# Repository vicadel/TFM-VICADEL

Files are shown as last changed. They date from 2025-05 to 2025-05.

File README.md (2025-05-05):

# 3D-Printed Myoelectric Prosthesis Controlled by EMG Signals with BITalino Sensorization

## 📚 Project Description

This repository contains the complete development of the **Master's Thesis (TFM)** titled:

> **Design, Fabrication, and Optimization of a 3D-Printed Myoelectric Prosthesis Controlled by EMG Signals with BITalino Sensorization**

Authored by **Víctor Alonso del Moral** for the **Master's Degree in Electronic Engineering** at the **Universidad de Valencia (UV)**.

The project involves the design, manufacturing, and experimental validation of a robotic upper-limb prosthesis controlled via electromyographic (EMG) signals using the **BITalino kit** and an **ESP32** microcontroller. 
The system integrates computer vision control through **OpenCV**, and is optimized for 3D printing in **PETG** material.

---

## 📂 Repository Structure

- **README.md**: Main documentation.
- **LICENSE**: GNU GPL v3.0 license for open use.
- **docs/**: Full technical documentation (report, appendices, diagrams, 3D models).
- **hardware/**: 3D models (STL), electronic schematics (Fritzing), electronic configurations.
- **software/**:
  - **Arduino/**: Code for ESP32 (servo control, EMG interpretation).
  - **Python/**: Scripts for EMG data acquisition from BITalino and vision-based gesture control (OpenCV).
- **tests/**: Functional validation test results.
- **designs/**: CAD files for modified and custom-designed parts.

---

## 🛠️ Technologies Used

- **Microcontroller**: ESP32 WeMos R32 D1
- **Signal Acquisition System**: BITalino (r)evolution Plugged Kit BLE
- **EMG Sensors**: Aoutecen
- **Servomotors**: MG996R
- **3D Design**: SolidWorks, Tinkercad
- **Manufacturing**: FDM 3D Printing (PETG)
- **3D Printing Software**: Ultimaker Cura
- **Programming**: Arduino IDE, Python (PySerial, OpenCV)
- **Circuit Modeling**: Fritzing

---

## 🚀 Installation and Usage

1. Clone this repository:
   ```bash
   git clone https://github.com/vicadel/TFM-3D-Printed-Myoelectric-Prosthesis.git
   ```

2. Load the Arduino code:
   - Open Arduino IDE.
   - Select the `ESP32 Dev Module` board.
   - Upload the sketch from `software/Arduino/`.

3. Run the EMG acquisition system:
   - Install Python dependencies:
     ```bash
     pip install bitalino pyserial opencv-python
     ```
   - Run the EMG or vision control scripts from `software/Python/`.

4. Follow detailed instructions in `docs/memoria_TFM.pdf` for assembly, calibration, and testing.

---

## 📈 Project Status

✅ Mechanical design optimized  
✅ Functional EMG sensorization  
✅ Wireless control using ESP32  
✅ Gesture control via computer vision  
✅ Experimental validation completed

---

## 🔮 Future Work

- Integration of artificial intelligence for EMG gesture recognition.
- Development of a mobile app for calibration and control.
- Design of a custom PCB for system integration.
- Implementation of haptic feedback systems.

---

## 📜 License

This project is licensed under the **GNU General Public License v3.0**.  
See the `LICENSE` file for more details.

---

## 🙌 Acknowledgements

- Thanks to the Open Source community for providing essential tools.
- Personal thanks to my family and friends for their constant support.

---

> Created with passion, dedication, and a drive for innovation. 🚀

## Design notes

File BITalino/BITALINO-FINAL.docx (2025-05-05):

# 6.7. Adquisición de Señales EMG con BITalino: Fundamentos, Procesamiento y Aplicaciones

## 6.7.1. Introducción a la Adquisición de Señales EMG

El kit BITalino (r)evolution Plugged Kit BLE/BT es una plataforma modular de adquisición biomédica diseñada específicamente para facilitar el estudio, la monitorización y la integración de señales fisiológicas en contextos portátiles y de investigación aplicada. Está compuesto por una unidad central de control (MCU) y una serie de módulos sensores enchufables que permiten la captación precisa de biopotenciales como EMG, ECG y EEG, además de otras variables como la conductancia de la piel (EDA), la aceleración (ACC) o la temperatura corporal.

Cada módulo de BITalino ha sido diseñado para cumplir los requisitos específicos de su tipo de señal, con una arquitectura electrónica independiente que incluye preamplificación, filtrado analógico, acondicionamiento y salida analógica ya lista para ser digitalizada por la MCU. La placa base incluye un sistema de adquisición con resolución de 10 bits, transmisión Bluetooth 4.0 BLE y conectividad por UART, lo que permite tanto la transmisión inalámbrica de datos en tiempo real como su almacenamiento para análisis posteriores.

3.2 Funcionamiento interno del sistema BITalino

El funcionamiento del sistema puede dividirse en cinco etapas principales:

1. Captación de la señal:
- A través de electrodos de superficie (Ag/AgCl) conectados directamente a los sensores modulares.
- El tipo de electrodos y su colocación son clave para garantizar una captación de señal limpia, especialmente en señales EMG.
2. Acondicionamiento analógico en el módulo sensor:
- Cada módulo contiene un amplificador de instrumentación de alta ganancia (1009 para EMG). Elimina señales comunes con CMRR > 80 dB.
- Se aplica un filtro analógico paso banda específico del tipo de señal (ej. EMG: 20–500 Hz).
- Alta impedancia de entrada para evitar pérdida de señal debido al contacto con la piel.
3. Conversión Analógico-Digital (ADC):
- El módulo MCU centraliza la conversión con una resolución de 10 bits (1024 niveles).
- Se digitalizan las señales preacondicionadas que llegan de los módulos por cable Plugged.
- El muestreo puede configurarse entre 1 Hz y 1000 Hz (valor típico en EMG: 1000 Hz).
4. Multiplexación y estructura de paquetes:
- Cada canal se multiplexa y se estructura en tramas tipo UART (8N1) o BLE.
- Las tramas digitales incluyen cabecera, ID de canal, timestamp y valor digitalizado.
5. Transmisión inalámbrica o por cable:
- BLE: permite comunicación con PC, móviles, microcontroladores o apps como OpenSignals.
- UART: conexión a software como OpenSignals o a microcontroladores como la ESP32.

3.3. BITalino: Módulos Disponibles y Aplicación en la Adquisición de EMG

- EMG (Electromiografía): Captura señales eléctricas generadas por la actividad muscular.
- ECG (Electrocardiografía): Registra la actividad eléctrica del corazón.
- EDA (Actividad Electrodérmica): Mide la conductancia de la piel relacionada con la respuesta fisiológica emocional.
- ACC (Acelerómetro): Detecta movimiento y orientación espacial en tres ejes.
- LUX (Sensor de luz): Mide la intensidad de luz ambiental.
- Temperatura: Registra la temperatura corporal o ambiental.
- EEG (Electroencefalografía): Captura señales cerebrales para análisis neuronal.
- MCU (Potencia y Comunicación): Centraliza la gestión del sistema, proporcionando comunicación Bluetooth.
- BTN (Push Button): Interruptor digital para sincronización y marcado manual de eventos.

Estos módulos pueden conectarse e integrarse de forma flexible, permitiendo adaptarse a diversas aplicaciones biomédicas, deportivas y de investigación.

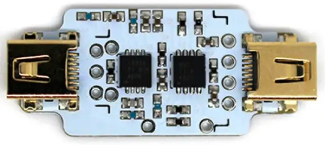
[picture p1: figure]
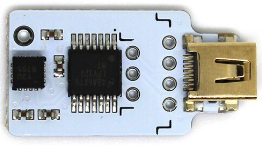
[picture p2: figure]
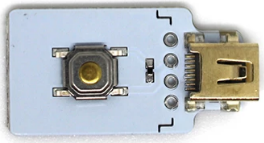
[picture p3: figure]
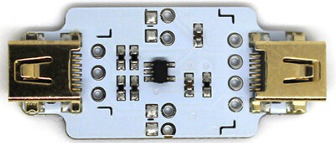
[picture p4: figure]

Ilustración 1 - Vista general de los diferentes módulos que componen el ecosistema BITalino: sensores de EMG, EDA, ACC, ECG, EEG, temperatura, luz, pulsador y módulo MCU. Cada uno de ellos se puede intercambiar e integrar en configuraciones personalizadas según la aplicación biomédica deseada.
(Agradecimientos a pluxbiosignals.com)

### 3.4. Módulos candidatos para la Adquisición y Análisis de señales EMG

En el apartado anterior se han mencionado los diferentes sensores disponibles en BITalino. Sin embargo, en este apartado nos centraremos exclusivamente en aquellos que pueden utilizarse en la adquisición de señales EMG, fundamentales para el análisis de la actividad muscular, el control de dispositivos y la investigación biomédica. La correcta selección y combinación de estos sensores permite una adquisición más precisa y completa de la señal, reduciendo la presencia de artefactos y mejorando la interpretación de los datos.

## 3.1 Módulo EMG (Electromiografía)

El módulo EMG de BITalino es el sensor principal para la medición de la actividad muscular, utilizado para la medición del electromiograma. Su funcionamiento se basa en la detección de los impulsos eléctricos generados por la contracción de los músculos, capturados mediante electrodos superficiales colocados estratégicamente sobre la piel.

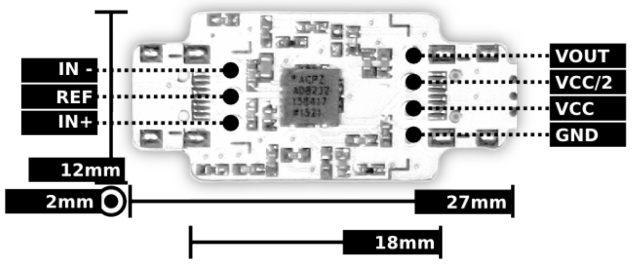
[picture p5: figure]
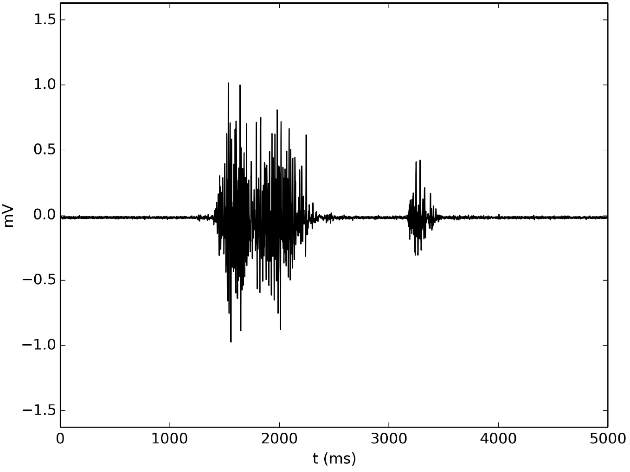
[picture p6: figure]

Ilustración 2 - Vista del módulo EMG con sus conexiones de entrada y salida, junto a una señal EMG real en milivoltios captada durante la contracción muscular (Agradecimientos a pluxbiosignals.com)

Este sensor cuenta con una alta ganancia para amplificar la señal y permitir su procesamiento sin pérdidas. Además, incorpora un filtrado para reducir interferencias externas, como el ruido de la red eléctrica o los artefactos generados por el movimiento del usuario.

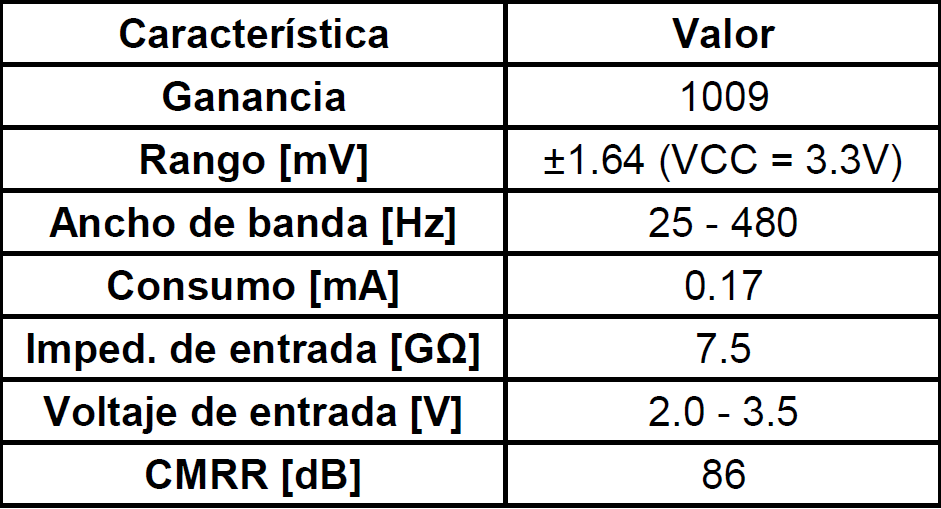
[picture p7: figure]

Tabla 1 – Características principales del Módulo EMG

Una característica fundamental del módulo EMG es su alta impedancia de entrada, lo que permite captar señales de baja amplitud con precisión, minimizando los efectos de la resistencia de contacto entre la piel y los electrodos. La calidad de la señal puede verse afectada por factores como la sudoración, la colocación de los electrodos o la presencia de ruido electromagnético en el entorno.

Este sensor opera dentro de un rango de voltajes óptimo para integrarse en sistemas embebidos, gracias a su bajo consumo energético, es ideal para aplicaciones portátiles. Su uso es común en el desarrollo de prótesis controladas por EMG, estudios de ergonomía, monitorización del rendimiento muscular en el deporte y rehabilitación de pacientes con trastornos neuromusculares.

Otro aspecto relevante es la conversión de los valores digitales adquiridos mediante el ADC para obtener representaciones en unidades de milivoltios. Para esto, se emplea una función de transferencia específica que tiene en cuenta la ganancia del sensor y el voltaje de referencia.

### 5.1.1 Función de Transferencia para el Sensor EMG

La conversión de los valores digitales obtenidos mediante el ADC a unidades de voltaje en el sensor EMG se realiza mediante la siguiente ecuación, permitiendo transformar los datos adquiridos en valores comprendidos entre -1.64 mV y 1.64 Mv.

3.1 Etapas del procesamiento de señal

1. Captura por electrodos: Configuración bipolar con tres electrodos: activo (+), referencia (-), y tierra. Deben colocarse alineados con las fibras musculares.
2. Amplificación diferencial: Con ganancia fija de 1009. Elimina señales comunes con CMRR > 80 dB.
3. Filtrado analógico: Filtro paso-banda entre 20–500 Hz.
4. Conversión analógico-digital (ADC): Resolución de 10 bits. Frecuencia de muestreo ajustable; 1000 Hz utilizada en este proyecto.
5. Transmisión: Vía BLE o UART a software como OpenSignals o a microcontroladores como la ESP32.

EMG(V)=(((ADC)/(2^n)-1/2)×VCC)/(G_(EMG))

EMG(mV)=EMG(V)×1000

Donde:

- VCC representa la tensión de alimentación del sensor, cuyo valor es 3.3V.
- G_(EMG) es la ganancia del sensor, establecida en 1009.
- ADC se refiere al valor digital obtenido en el proceso de conversión.
- n es la resolución del conversor analógico-digital, con un valor por defecto de 10 bits.

## 5.2 Módulo EDA (Actividad Electrodérmica)

El sensor EDA de BITalino está diseñado para medir la actividad electrodérmica de la piel, proporcionando información sobre la conductancia cutánea. Aunque su función principal está enfocada en estudios de respuestas fisiológicas relacionadas con el estrés o la actividad del sistema nervioso autónomo, también puede complementar la adquisición de señales EMG.

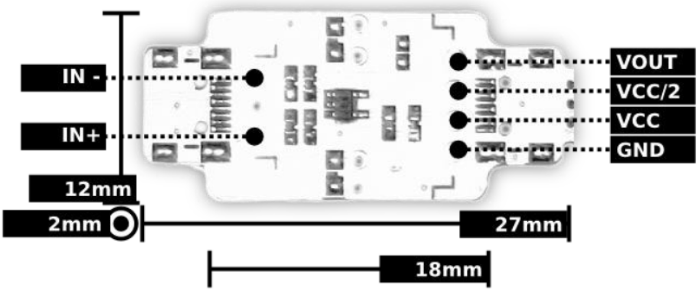
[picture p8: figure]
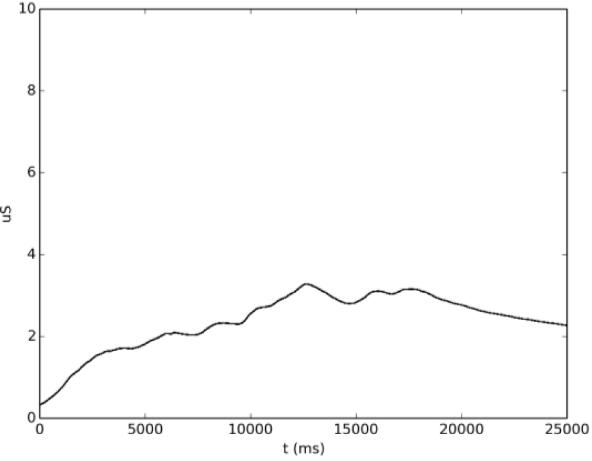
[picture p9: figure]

Ilustración 3 - Imagen del sensor EDA con su esquema de pines y gráfica de conductancia (en µS) frente al tiempo, correspondiente a una respuesta fisiológica gradual.
(Agradecimientos a pluxbiosignals.com)

3.X.1 Etapas del procesamiento de señal EDA

1. Captura por electrodos: Se utilizan dos electrodos colocados en las falanges distales de los dedos índice y medio de la mano no dominante.
2. Conversión de resistencia a voltaje: La variación de la resistencia de la piel es transformada en un voltaje proporcional por medio de un divisor resistivo interno.
3. Filtrado analógico: Se utiliza un filtro pasa-bajo para eliminar ruido de alta frecuencia y garantizar estabilidad de la señal.
4. Conversión analógico-digital (ADC): Resolución de 10 bits, con una frecuencia de muestreo más baja que EMG (recomendada: 10–100 Hz).
5. Transmisión: Vía BLE o UART para su análisis en OpenSignals o software personalizado.

El principio de funcionamiento del sensor EDA se basa en la variación de la resistencia de la piel, la cual cambia según el nivel de hidratación y la actividad de las glándulas sudoríparas. Estos cambios se traducen en variaciones en la conductancia cutánea, las cuales son captadas mediante electrodos y convertidas en una señal eléctrica proporcional. La presencia de sudor, por ejemplo, aumenta significativamente la conductividad entre los electrodos, lo que puede afectar la calidad de otras señales fisiológicas como la EMG, al modificar el contacto piel-electrodo.

Su integración junto al módulo EMG en entornos de adquisición multisensorial permite estudiar la relación entre la activación muscular y el estado fisiológico del usuario. Esto resulta especialmente útil en contextos de fatiga muscular, análisis de estrés o sistemas de biofeedback. Además, el módulo EDA de BITalino destaca por su bajo consumo energético y alta sensibilidad, lo que lo convierte en una herramienta eficaz en investigaciones de neurociencia, psicología aplicada y control de interfaces basadas en parámetros fisiológicos.

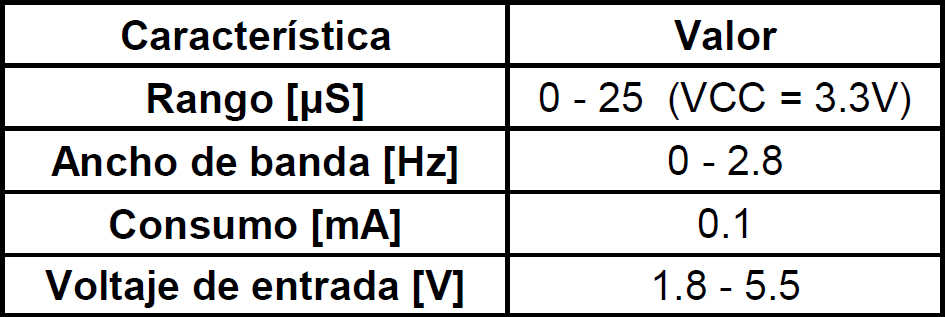
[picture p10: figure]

Tabla 2 - Características principales del Módulo EDA

### 5.2.1 Función de Transferencia para el Sensor EDA

El sensor de actividad electrodérmica (EDA) convierte la resistencia de la piel en valores de conductancia expresados en microsiemens (μS). La ecuación que rige esta transformación es:

R(MΩ)=1- (ADC)/(2^n)

EDA(μS)=1/(R(MΩ))

Donde:

- R(MΩ) representa la resistencia medida por el sensor en megaohmios.
- ADC es el valor digitalizado obtenido de la señal.
- n corresponde al número de bits de resolución del ADC, fijado en 10 bits por defecto.

"La frecuencia de muestreo recomendada para la señal EDA es menor en comparación con la EMG, ya que la respuesta galvánica de la piel varía lentamente. Además, el uso de electrodos de plata/cloruro de plata (Ag/AgCl) mejora la estabilidad de la medición y reduce la impedancia de contacto, optimizando la calidad de la señal."

## 5.3 Módulo ACC (Acelerómetro)

El módulo ACC de BITalino mide la aceleración en tres ejes espaciales, proporcionando datos sobre el movimiento y la orientación del dispositivo. Aunque no mide directamente la actividad muscular, su uso combinado con el sensor EMG permite mejorar el análisis de la señal al correlacionarla con el movimiento del cuerpo.

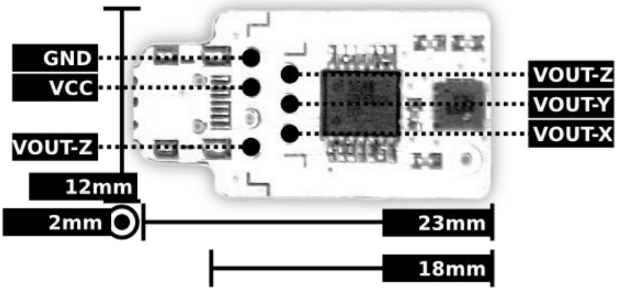
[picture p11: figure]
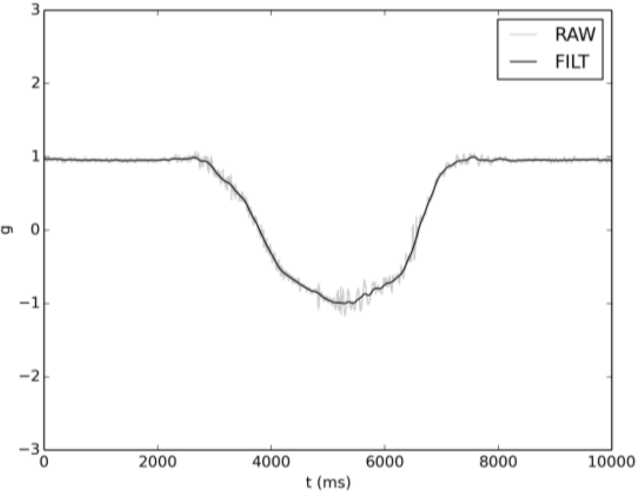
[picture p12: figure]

Ilustración 4 - Representación del acelerómetro con salidas por eje (X, Y, Z), junto a una señal de aceleración donde se compara la señal sin filtrar y la filtrada. (Agradecimientos a pluxbiosignals.com)

3.X.1 Etapas del procesamiento de señal

1. Captura por sensores MEMS: Cada eje del acelerómetro capta variaciones de aceleración debidas al movimiento.
2. Conversión de aceleración a voltaje: El sensor MEMS produce un voltaje analógico proporcional a la aceleración detectada.
3. Filtrado analógico: Se aplica un filtro pasa-bajo interno para evitar oscilaciones de alta frecuencia y ruidos mecánicos.
4. Conversión analógico-digital (ADC): Conversión a 10 bits por canal; frecuencia típica: 100–500 Hz.
5. Transmisión: Enviado vía BLE o UART en tiempo real.

El sensor ACC de BITalino permite medir la aceleración en los tres ejes del espacio (X, Y, Z), siendo una herramienta clave en estudios de biomecánica, rehabilitación y control por gestos. Su integración junto al módulo EMG facilita el análisis conjunto de la postura, el desplazamiento y la activación muscular, lo cual resulta útil en el estudio de la marcha, análisis ergonómico o sistemas de asistencia robótica.

Además, el acelerómetro resulta esencial para detectar y corregir artefactos de movimiento en las señales EMG. Al identificar aceleraciones bruscas, el sistema puede discernir entre una contracción muscular real y una alteración debida a desplazamiento involuntario del sensor. Su bajo consumo energético y alta sensibilidad lo hacen adecuado para sistemas portátiles, permitiendo una monitorización continua sin comprometer la autonomía. También destaca por su capacidad para registrar cambios sutiles, lo que lo hace especialmente valioso en estudios de control motor y equilibrio postural.

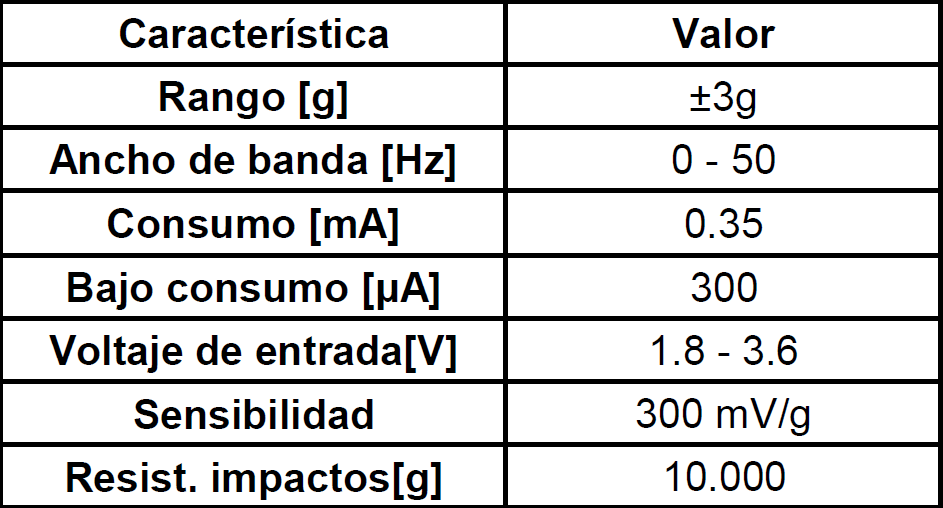
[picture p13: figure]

Tabla 3 - Características principales del Módulo ACC

### 5.3.1 Función de Transferencia para el Sensor ACC

El sensor acelerómetro convierte los valores digitales adquiridos por el ADC en aceleración expresada en g (gravedad terrestre). La ecuación utilizada para esta conversión es:

ACC(g)=(ADC-C_(min))/(C_(max-) C_(min))×2-1

Donde:

- ADC es el valor digital obtenido por el convertidor analógico-digital.
- C_(min) representa el menor valor registrado durante la calibración del sensor.
- C_(max) es el valor máximo captado durante la calibración.

Para calibrar correctamente el acelerómetro, se recomienda realizar una rotación completa de 360° en cada eje, asegurando que se alcancen los valores de referencia de ±1 g. El rango de medición del módulo ACC de BITalino es de ±3 g, suficiente para la mayoría de las aplicaciones biomédicas y ergonómicas. Para mejorar la estabilidad de la señal y reducir el ruido, se aconseja aplicar filtrado digital pasa-bajo o promediar los datos adquiridos.

## 5.4 Módulo BTN (Push Button)

El módulo BTN de BITalino es un interruptor digital que permite detectar pulsaciones momentáneas. Aunque no es un sensor fisiológico, su integración en sistemas de adquisición de señales EMG permite la sincronización y el marcado de eventos.

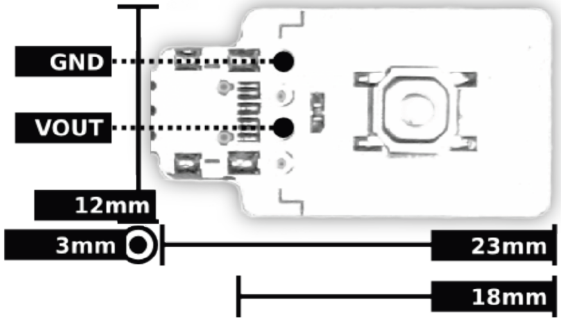
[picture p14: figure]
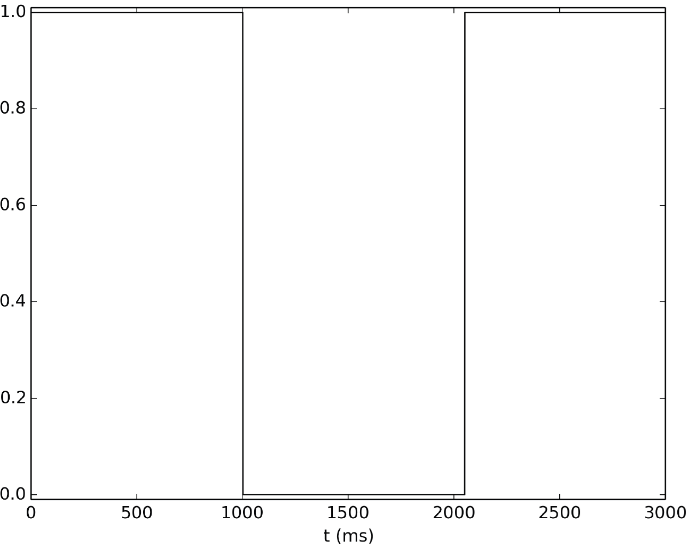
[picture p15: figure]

Ilustración 5 - Visualización del módulo de botón junto a una señal binaria en función del tiempo, que indica la detección de dos pulsaciones momentáneas. (Agradecimientos a pluxbiosignals.com)

3.X.1 Etapas del procesamiento de señal

1. Activación por usuario: Pulsación manual sobre el botón.
2. Lectura de estado digital: El estado del botón es leído como alto (1) o bajo (0).
3. Debouncing electrónico: Se elimina el rebote mediante un filtro RC o digital (firmware).
4. Codificación digital: La transición de estado se codifica en un paquete binario.
5. Transmisión: Se envía mediante BLE o UART para sincronizar eventos en OpenSignals o microcontroladores.

Tabla 4 - Características principales del Módulo BTN

El módulo BTN se utiliza principalmente como herramienta de control dentro de experimentos donde es necesario identificar momentos clave en la adquisición de señales fisiológicas. Su función más habitual es la marcación de eventos, como el inicio o el fin de una contracción muscular voluntaria durante pruebas con EMG, facilitando la posterior segmentación y análisis de los datos registrados. También puede utilizarse en sistemas interactivos como confirmación o activación de comandos dentro de un flujo de control.

Gracias a su diseño de bajo consumo energético y su integración directa con el resto de los módulos del sistema BITalino, el botón permite sincronización precisa de eventos en tiempo real. Su tiempo de respuesta es prácticamente instantáneo, lo que lo hace ideal para protocolos que requieren alta precisión temporal, como el control de prótesis, estudios de activación muscular o biofeedback. Su simplicidad y eficacia lo convierten en una herramienta auxiliar muy valiosa dentro de sistemas de adquisición multisensorial.

Conclusión

El sistema BITalino, mediante su arquitectura modular y su compatibilidad con múltiples señales fisiológicas, ha demostrado ser una herramienta versátil para la adquisición y análisis biomédico. En este proyecto se han analizado sus cuatro módulos principales: EMG, EDA, ACC y BTN. Cada uno de ellos aporta información complementaria que permite una caracterización más completa de la actividad del usuario. El EMG ha sido la base para la detección de contracciones musculares, el EDA permite interpretar el estado autonómico, el ACC añade contexto cinemático al movimiento corporal, y el BTN aporta control manual y marcado de eventos clave.

Si bien todos los módulos han sido utilizados durante la fase experimental para comprender su comportamiento y posibilidades de integración, únicamente el EMG ha sido implementado de forma funcional en los códigos del TFM. Este módulo ha permitido controlar en tiempo real la prótesis robótica desarrollada, mediante programación en Python y comunicación con una placa ESP32. La integración completa del resto de módulos, especialmente con técnicas de fusión sensorial y algoritmos de aprendizaje automático, se plantea como un avance futuro que permitirá dotar al sistema de mayor robustez, adaptabilidad y precisión en entornos dinámicos reales.

## 6. Proceso Técnico de Adquisición de la señal

### 6.1. Captura y Adquisición Inicial de la Señal EMG

La adquisición de señales EMG con BITalino comienza con la colocación precisa de electrodos superficiales sobre el músculo de interés. Se recomienda el uso de electrodos pre-gelificados para asegurar una baja impedancia y un contacto estable. La configuración preferida es la bipolar, donde dos electrodos activos se colocan alineados con las fibras musculares, y un electrodo de referencia se sitúa en una región ósea o de baja actividad muscular, como el codo o la clavícula.

BITalino emplea sensores EMG en configuración bipolar, lo cual representa una elección técnica clave frente a la alternativa unipolar. Esta configuración bipolar permite una mayor inmunidad al ruido de modo común, lo que mejora notablemente la calidad de la señal y reduce las interferencias externas, algo fundamental en aplicaciones como el control de prótesis o el análisis de la actividad muscular. Además, al colocar dos electrodos activos directamente sobre el músculo, se logra una detección más precisa y localizada, ideal para estudios donde se requiere alta resolución, como en biofeedback o rehabilitación. A diferencia de la configuración unipolar, que es más vulnerable al ruido y menos específica, la bipolaridad garantiza una mayor fiabilidad, simplicidad en el montaje y robustez durante el uso, especialmente en entornos no clínicos como el educativo o de investigación aplicada. Por tanto, remarcar que el sistema BITalino trabaja con sensores bipolares es esencial para justificar tanto el diseño del sistema como la calidad de los resultados obtenidos.

### 6.2. Amplificación Diferencial y Filtrado Analógico

Tras la captura inicial, la señal EMG, típicamente de muy baja amplitud (aproximadamente entre 5 y 20 µV), es sometida a una amplificación diferencial mediante circuitos integrados específicos del módulo EMG del BITalino. Este amplificador posee una ganancia alta (aproximadamente 1009) y un alto rechazo del modo común (CMRR) de 86 dB para minimizar ruido y artefactos externos.

Simultáneamente, se aplican filtros analógicos integrados que operan en un rango de frecuencia de 20-500 Hz para eliminar interferencias de baja frecuencia (movimiento, respiración) y alta frecuencia (ruido electromagnético).

### 6.3. Conversión analógico-digital (ADC)

La señal analógica amplificada y filtrada se convierte a formato digital mediante un conversor analógico-digital (ADC) de 10 bits, integrado en el sistema BITalino. Este ADC tiene una tasa de muestreo ajustable, típicamente configurada a 1000 Hz, cumpliendo el teorema de Nyquist para capturar señales EMG sin aliasing hasta frecuencias de 500 Hz:

f_(muestreo) ≥2× f_(maxEMG)

### 6.4. Procesamiento Digital Avanzado

La señal digitalizada EMG se procesa mediante varias etapas técnicas detalladas a continuación:

- Filtrado Digital Avanzado: Implementación de un filtro digital Butterworth paso-banda de cuarto orden (20-500 Hz) mediante software específico como OpenSignals o directamente en ESP32. Esto permite una limpieza adicional y más precisa de la señal capturada.
- Rectificación de la Señal: La señal EMG, originalmente alternante (AC), se rectifica mediante:

EMG_(rect(t)) =|EMG(t)|

Este paso convierte la señal en positiva, facilitando el análisis posterior de la envolvente muscular.

- Suavizado y Extracción de la Envolvente: Para obtener una representación más clara y continua de la actividad muscular, se aplica un filtro digital de media móvil o un filtro paso-bajo con ventana de suavizado de aproximadamente 0.5 segundos:

EMG_(suave(t) =) 1/N ∑_(i=t)^(t+N-1) EMG_(rect(i))

Este proceso estabiliza la señal y permite un análisis más preciso y menos susceptible al ruido residual.

### 6.5. Extracción de Características Específicas

La señal suavizada pasa por la extracción de características fundamentales para análisis cuantitativo y control protésico. Las características típicas incluyen:

- RMS (Root Mean Square):

√(1/N ∑_(i=1)^N EMG^2 _(rect) (i))

- Valor Medio Absoluto (MAV):

1/N∑_(i=1)^N |EMG(i)|

Estas características proporcionan parámetros sólidos para el reconocimiento y control preciso basado en EMG.

6.6 Pruebas experimentales de adquisición de señales EMG en el hombro y antebrazo con BITalino.

Con el objetivo de identificar las ubicaciones más eficaces para la adquisición de señales electromiográficas (EMG) aplicadas al control de una prótesis mioeléctrica, se ha desarrollado un protocolo experimental basado en la utilización del kit BITalino (r)evolution Plugged Kit BLE/BT. El enfoque adoptado se centra en una configuración distribuida de hasta nueve electrodos por prueba, empleando cuatro sensores BITalino simultáneamente. Esto permite evaluar la calidad y estabilidad de las señales recogidas en diferentes regiones musculares del miembro superior y el muñón, así como su pertinencia para su integración en algoritmos de control protésico.

6.6.1 Configuración de pruebas y distribución de electrodos

Se diseñaron pruebas experimentales enfocadas en dos zonas clave del miembro superior: el hombro y el antebrazo. En cada una se colocaron 9 electrodos (4 sensores) para evaluar la calidad y estabilidad de las señales EMG en diferentes regiones musculares implicadas en el control de una prótesis mioeléctrica.

- Prueba 1: Zona del hombro

Objetivo: Registrar actividad del deltoides y estabilizadores en movimientos articulares.

- Sensor 1 (3 electrodos): Deltoides anterior/posterior, tierra en clavícula.
- Sensor 2 (2 electrodos): Deltoides medio.
- Sensor 3 (2 electrodos): Trapecio superior.
- Sensor 4 (2 electrodos): Pectoral mayor.

Movimientos: Apertura/cierre de la mano, rotación de muñeca, posiciones y dedos.

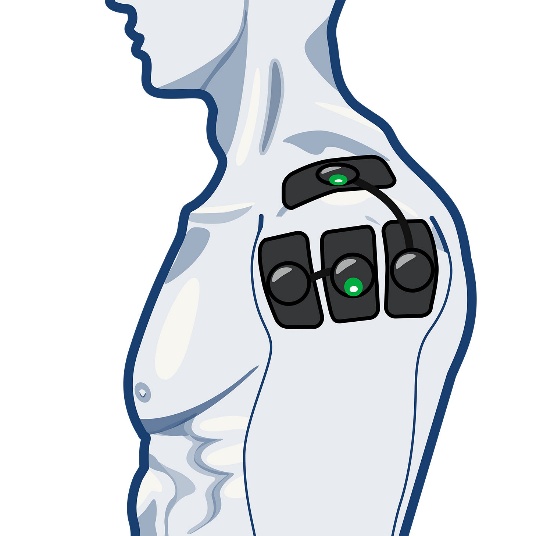
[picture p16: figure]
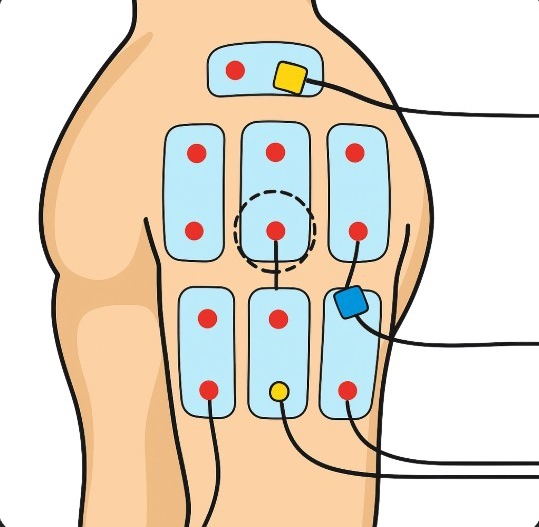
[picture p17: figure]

Ilustración 6 – Ejemplo visual de colocación de los electrodos en la zona del hombro

- Prueba 2: Zona del antebrazo

Objetivo: Captar señales durante flexión/extensión de muñeca y dedos.

- Sensor 1 (3 electrodos): Flexores superficiales de los dedos, tierra sobre superficie ósea.
- Sensor 2 (2 electrodos): Extensores comunes de los dedos.
- Sensor 3 (2 electrodos): Pronador redondo.
- Sensor 4 (2 electrodos): Supinador largo.

Movimientos: Apertura/cierre de la mano, rotación de muñeca, posiciones y dedos.

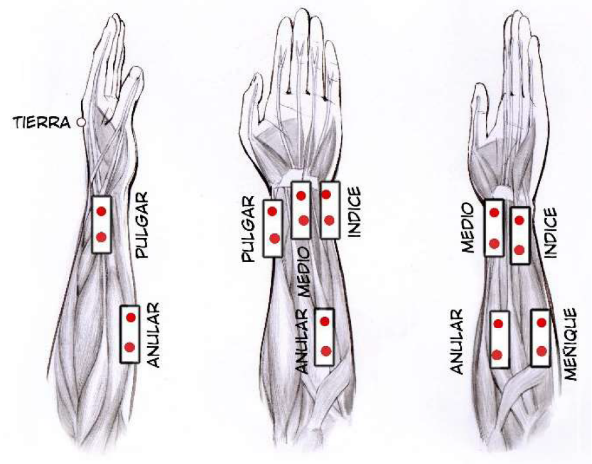
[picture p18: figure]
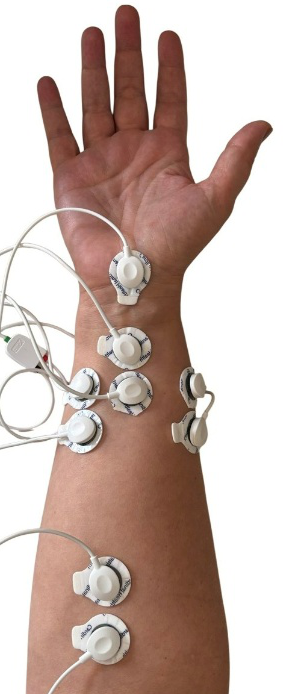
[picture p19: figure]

6.7 Configuración detallada de OpenSignals para la adquisición EMG

OpenSignals es el software oficial desarrollado por PLUX para la adquisición, visualización y exportación de datos capturados con los dispositivos BITalino. Su interfaz intuitiva y altamente configurable permite adaptar cada sesión experimental a las necesidades técnicas del estudio, garantizando calidad de señal, trazabilidad y compatibilidad con análisis posteriores.

6.7.1 Parámetros clave de configuración

- Tasa de muestreo seleccionada: La señal EMG contiene frecuencias de hasta 500 Hz. Según el teorema de Nyquist, para evitar aliasing y pérdida de información, es necesario muestrear al menos al doble de esa frecuencia. 1000 Hz permite capturar de forma precisa los detalles temporales y espectrales de la señal.
- Filtro digital aplicado: Elimina componentes de baja frecuencia (movimiento, respiración) y ruido de alta frecuencia (EMI).
- Visualización en tiempo real con envolvente: Permite observar la activación muscular con mayor claridad y detectar patrones en tiempo real.
- Grabación en formato .CSV: Pemite exportar los datos para análisis posteriores en MATLAB o Python.
- Conversión activada: Activar la opción "Converted Values" permite visualizar y exportar los datos directamente en milivoltios, aplicando internamente la función de transferencia del sensor EMG.
- Trigger (disparo por evento): Permite marcar el inicio de un ejercicio o una contracción muscular, sincronizando la señal con el instante deseado.

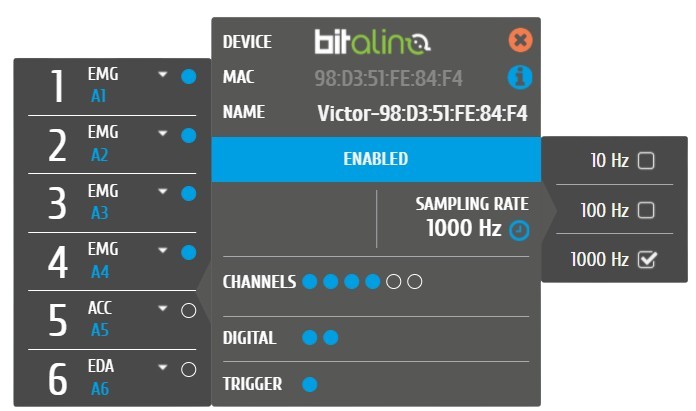
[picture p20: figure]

Ilustración 9 - Vista general del panel de conexión al kit BITalino y Pantalla de configuración del dispositivo en OpenSignals, donde se muestra la tasa de muestreo configurada a 1000 Hz, la activación de cuatro canales EMG (A1–A4), un canal de acelerómetro (A5) y EDA (A6). Se observa también la activación de los canales digitales y la función de trigger para registrar eventos (Agradecimientos a pluxbiosignals.com)

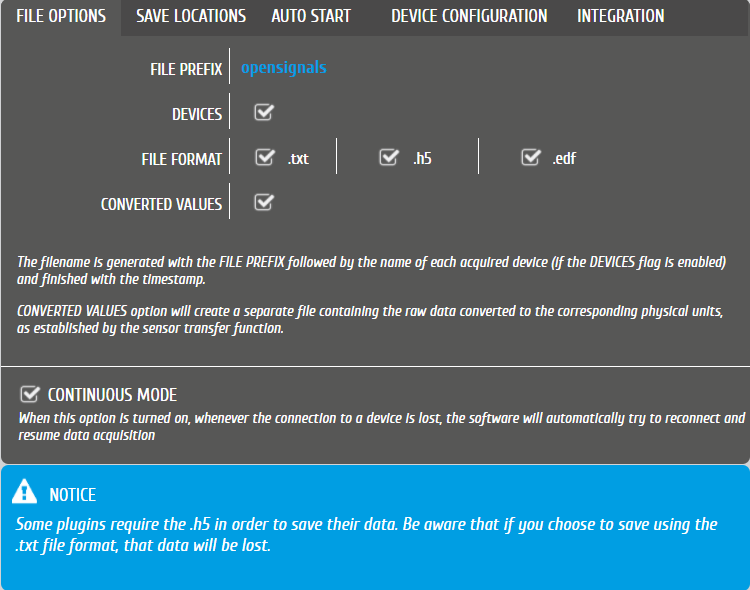
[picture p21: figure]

Ilustración 10 - Panel de configuración de guardado de datos donde se selecciona el formato de archivo (.txt, .h5, .edf), el prefijo del archivo, y la opción “Converted Values”, que permite exportar los datos con unidades físicas aplicando la función de transferencia (Agradecimientos a pluxbiosignals.com))

6.7.3 Integración con sensores complementarios

- Alta fidelidad de señal: con 1000 Hz se garantiza la captura de todo el contenido útil sin distorsión.
- Flexibilidad experimental: parámetros fácilmente adaptables según el tipo de sensor o el objetivo del experimento.
- Compatibilidad: OpenSignals exporta formatos estándar, permitiendo trabajar sin restricciones en entornos de análisis personalizados.
- Consumo de recursos: altas tasas de muestreo generan más datos, por lo que es importante planificar el almacenamiento y procesamiento previo.
- Sinergia con módulos adicionales: Durante la adquisición con OpenSignals, se utilizaron también módulos complementarios del sistema
- Combinaciones recomendadas:
- EMG + ACC: Reconocimiento de gestos + eliminación de interferencias por movimiento.
- EMG + EDA: Correlación entre fatiga muscular y respuesta electrodérmica.
- EMG + BTN : Segmentación precisa mediante pulsación sincronizada.

6.7.4 Ventana EMG Muscle Activations y ajustes recomendados

La ventana "EMG Muscle Activations" de OpenSignals permite detectar eventos musculares clave y personalizar filtros, unidades y parámetros de suavizado para facilitar el análisis. A continuación, se describen sus secciones principales y recomendaciones de configuración adaptadas al uso del kit BITalino en prótesis controladas por EMG:

- Asignación de disparador digital (ASSIGN DIGITAL TRIGGER)
- Permite asignar un canal digital como referencia para marcar eventos (por ejemplo, un botón físico).
- Si no se utilizan entradas digitales, puede ignorarse.
- Detección de activaciones (FIND ALL MUSCLE ACTIVATIONS)
- Detecta eventos basados en cambios digitales o temporales.
- Recomendación para BITalino:
- Opción: FROM DIGITAL ON TO 0.3 SEC
- Justificación: ajusta una ventana de detección para activar servos tras una contracción mantenida.

Opciones avanzadas de procesamiento (ADVANCED OPTIONS)

- Unidad: mV (milivoltios), ideal para precisión con señales crudas.
- Filtros recomendados:
- Bandpass: 20–500 Hz, orden 4 → ideal para capturar contenido útil EMG.
- Highpass y Lowpass opcionales según ruido presente.

Opciones de detección de activación (ACTIVATION DETECTION OPTIONS)

- Signal Smooth Window(0.5s): Suaviza sin perder respuesta rápida.
- Process on Another Channel: Desactivado, a menos que se use referencia cruzada.

Resultados de activación muscular (MUSCLE ACTIVATION RESULTS)

- Se muestra la contracción máxima (MVC) por canal:
- Si los valores son muy bajos (< 0.05 mV), ajustar filtros y trigger.

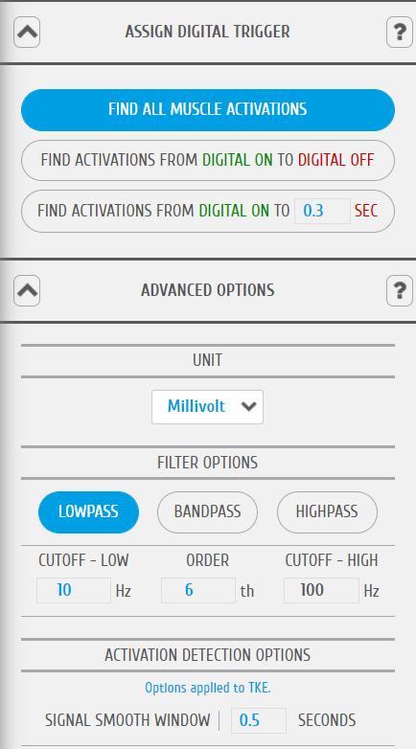
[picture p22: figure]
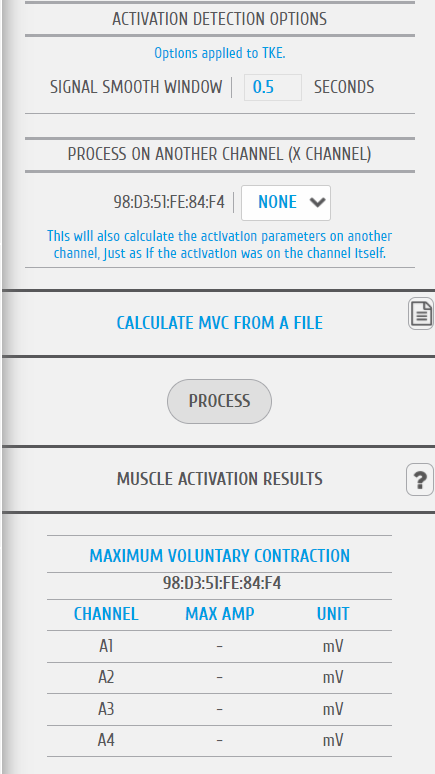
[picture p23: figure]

Ilustración 8 – (a) CoSe muestra la interfaz para detección de activaciones musculares en OpenSignals, incluyendo la asignación del trigger digital, el modo de detección por umbral temporal, y la selección de filtros. Se destacan la unidad en milivoltios, el filtro pasa banda recomendado (20–500 Hz) y la ventana de suavizado ajustada a 0.5 s.nfiguración avanzada de filtros y activación en la ventana EMG Muscle Activations. (b) Pantalla de resultados generados por la herramienta de activación muscular en OpenSignals. Muestra el uso de la opción “Process”, los ajustes de ventana de suavizado y canal, y los valores de máxima contracción para los canales A1 a A4 (Agradecimientos a pluxbiosignals.com)

Configuración óptima recomendada para tu sistema:

- Unidad: mV
- Filtro: Bandpass 500–1000 Hz, orden 4
- Ventana de suavizado: 0.5 s
- Trigger de activación: OFF o 0.3s

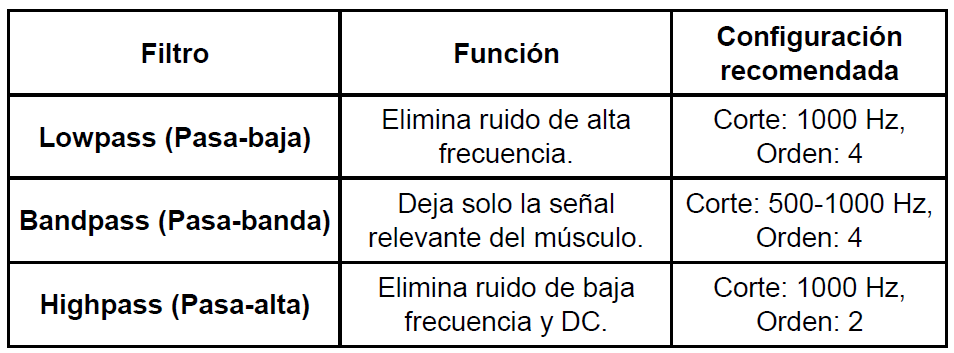
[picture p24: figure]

Ilustración 7 - Opciones de filtros para ayudar a mejorar la calidad de la señal EMG

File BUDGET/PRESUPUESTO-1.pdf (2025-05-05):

Nombre de la pieza | Parte Mecánica | Relleno(%) | Soporte | Pared(mm) | Peso (gr) | Precio(€)
i2_BASESOPORTE | i2_RightHand | 90 | Si | 3 | 800 | 16
i2_Adapter1109MG | i2_RightHand | 90 | Si | 3 | 65 | 1,3
i2_CoverFingerV3 | i2_RightHand | 90 | Si | 3 | 20 | 0,6
i2_FingersMoldX5V3 | i2_RightHand | 90 | Si | 3 | 100 | 2
i2_FingersTipX5V2 | i2_RightHand | 90 | Si | 3 | 30 | 0,6
i2_FingersX5V2 | i2_RightHand | 90 | Si | 3 | 75 | 1,5
i2_HandCover | i2_RightHand | 90 | Si | 3 | 78 | 1,6
i2_HandCover | i2_RightHand | 90 | Si | 3 | 72 | 1,5
i2_PalmCoverV2 | i2_RightHand | 90 | Si | 3 | 65 | 1,3
i2_PalmPDI | i2_RightHand | 90 | Si | 3 | 44 | 0,9
i2_PulleyX5V1 | i2_RightHand | 90 | Si | 3 | 15 | 0,3
i2_WristGearV1 | i2_RightHand | 90 | Si | 3 | 50 | 0,6
i2_WristLargeV2 | i2_RightHand | 90 | Si | 3 | 110 | 2,2
TOTAL I2_RIGHTHAND | | | | | 1524 30,4
Nombre de la pieza | Parte Mecánica | Relleno(%) | Soporte | Pared(mm) | Peso (gr) | Precio(€)
RobCableBackV3 | Forearm-servo-bed | 90 | Si | 3 | 14 | 0,4
RobCableFrontV3 | Forearm-servo-bed | 90 | Si | 3 | 17 | 0,45
RobRingV3 | Forearm-servo-bed | 90 | Si | 3 | 14 | 0,4
RobServoBedV6 | Forearm-servo-bed | 90 | Si | 3 | 47 | 1
Servo-pulleyX5 | Forearm-servo-bed | 90 | Si | 3 | 12 | 0,3
TensionerRightV1 | Forearm-servo-bed | 90 | Si | 3 | 15 | 0,35
TOTAL FOREARM | | | | | 119 2,9
Nombre de la pieza | Parte Mecánica | Relleno(%) | Soporte | Pared(mm) | Peso (gr) | Precio(€)
Bolt_entretoise7 | Right-Hand | 90 | Si | 3 | 15 | 0,35
Robpart2V4 | Right-Hand | 90 | Si | 3 | 40 | 1
Robpart3V4 | Right-Hand | 90 | Si | 3 | 51 | 1,3
Robpart4V4 | Right-Hand | 90 | Si | 3 | 66 | 1,8
Robpart5V4 | Right-Hand | 90 | Si | 3 | 83 | 2,15
TOTAL RIGHTHAND | | | | | 255 6,6
Nombre de la pieza | Parte Mecánica | Relleno(%) | Soporte | Pared(mm) | Peso (gr) | Precio(€)
CableHolderWristV5 | Rotation-Wrist | 90 | Si | 3 | 6 | 0,15
RotaWrist1V4 | Rotation-Wrist | 90 | Si | 3 | 41 | 1
RotaWrist2V3 | Rotation-Wrist | 90 | Si | 3 | 22 | 0,5
RotaWrist3V3 | Rotation-Wrist | 90 | Si | 3 | 11 | 0,3
WristGearsV5 | Rotation-Wrist | 90 | Si | 3 | 12 | 0,3
TOTAL ROTATION-WRIST | | | | | 92 2,25
Peso (gr) | Precio(€)
PRESUPUESTO TOTAL PROTESIS | 1990 42,15

# Presupuesto apartado Bloque Mecánico Impresión 3d Peso y Precio

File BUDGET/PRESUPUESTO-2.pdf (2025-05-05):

Componentes | Cantidad | Precio unitario (€) | Precio total (€)
BITalino (r)evolution Plugged Kit BLE/BT | 1 | 226,87 | 226,87
Sensor Cable | 4 | 12,1 | 48,4
2-Lead Electrode Cable | 4 | 18,15 | 72,6
3-Lead Electrode Cable | 1 | 23,59 | 23,59
700 mAh 3.7V Battery | 1 | 9,68 | 9,68
(EMG) Sensor | 5 | 12,1 | 60,5
3D Printed Box | 1 | 12,1 | 12,1
Ag/AgCl Electrodes (50) | 1 | 30,25 | 30,25

483,99

## Presupuesto apartado Instrumentación y Adquisición de señal

Presupuesto total apartado Instrumentacion y Adquisición de

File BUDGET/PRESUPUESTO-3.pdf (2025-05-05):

Componentes | Cantidad | Precio unitario (€) | Precio total (€)
ESP32 Wemos R32 | 1 | 6,99 | 6,99
Shield V5 | 1 | 3,5 | 3,5
HC-05 Bluetooth Module | 1 | 4,89 | 4,89
12V – 5V Convertidor | 1 | 3,29 | 3,29
Switch | 10 | 0,143 | 1,43
T Connector | 10 | 0,226 | 2,26
Push Button | 10 | 0,242 | 2,42
Slide Switch | 10 | 0,114 | 1,14
RGB LED (Cátodo Común) | 1 | 0,189 | 0,189
1000mAh 11.1VBattery | 1 | 12,99 | 12,99
Total | 46 | | 39,099
Componentes | Cantidad | Precio unitario (€) | Precio total (€)
Tornillos M3 x 16mm | 100 | 0,03 | 3
Tornillos M3 x 4mm | 100 | 0,02 | 2
Tornillo M3 x 12mm | 20 | 0,05 | 1
Tornillos M1.5 x 4mm | 100 | 0,03 | 3
Muelles 3/16″ x 1-3/4 | 10 | 0,25 | 2,5
Total | 330 | | 11,5
Componentes | Cantidad | Precio unitario (€) | Precio total (€)
Servomotores SG-90 | 10 | 1,1 | 11
Servomotores PDI-6225 | 6 | 5 | 30
Servomotores MG996R | 6 | 4,5 | 27
Sensores Hall AH3503 | 10 | 0,2 | 2
Imánes (2.5x1mm) | 100 | 0,01 | 1
Total | 132 | | 71
Componentes | Cantidad | Precio unitario (€) | Precio total (€)
Cinta de 16 hilos de 3 metros | 1 | 3 | 3
Cable de pesca 0.8x200LB | 3 | 15 | 15
Tubo de teflón 1.5X 2.5-1m | 6 | 1,5 | 9
Total | 10 | | 27

148,599

Componentes Eletrónicos

Tornillería y fijaciones

Motores y Sensores

Cables y líneas de conexión

PRESUPUESTO TOTAL COMPONENTES

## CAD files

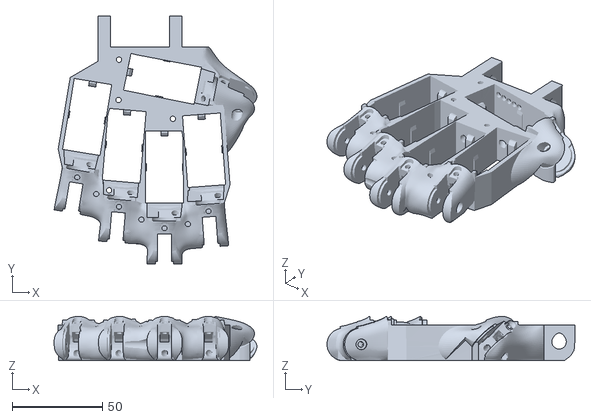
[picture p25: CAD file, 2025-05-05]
PLANOS STL/i2HandVicadel/i2_WristLargeV2.stl
112.6 x 137.7 x 24.5

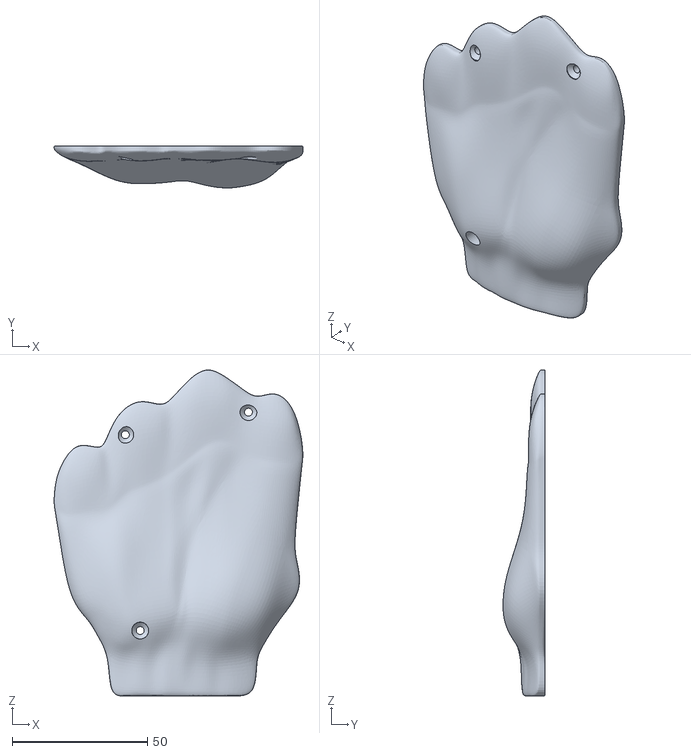
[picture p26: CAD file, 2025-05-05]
PLANOS STL/i2HandVicadel/i2_PalmCoverV2.stl
92.0 x 15.5 x 120.7

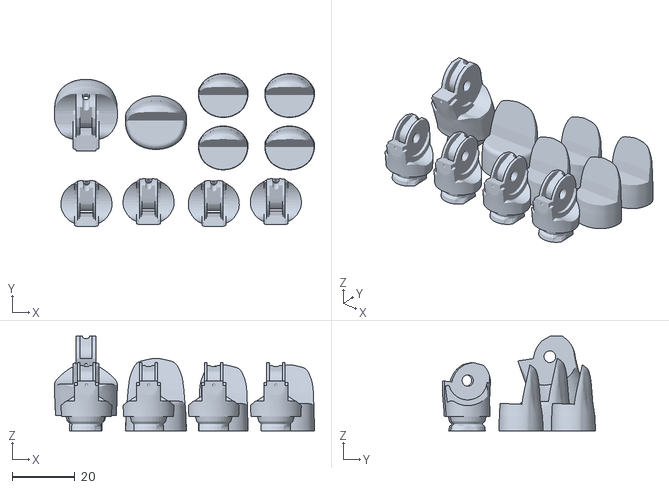
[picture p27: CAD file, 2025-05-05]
PLANOS STL/i2HandVicadel/i2_FingersTipX5V2.stl
82.9 x 48.7 x 30.2

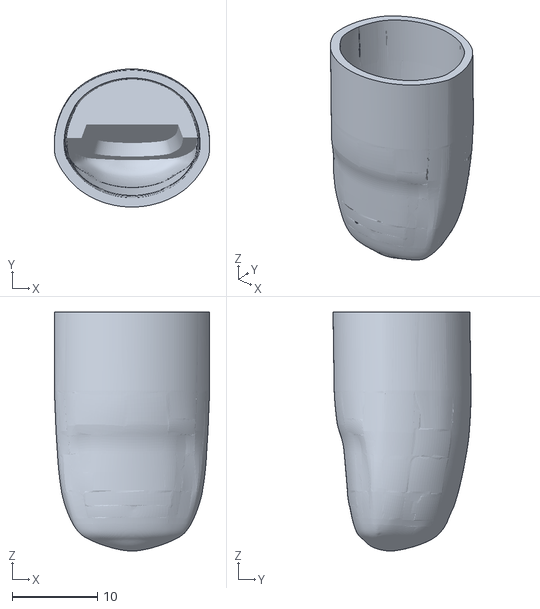
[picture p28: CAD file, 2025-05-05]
PLANOS STL/i2HandVicadel/Finger_TipV1_with_shallow_magnet_hole.stl
18.3 x 16.2 x 28.1

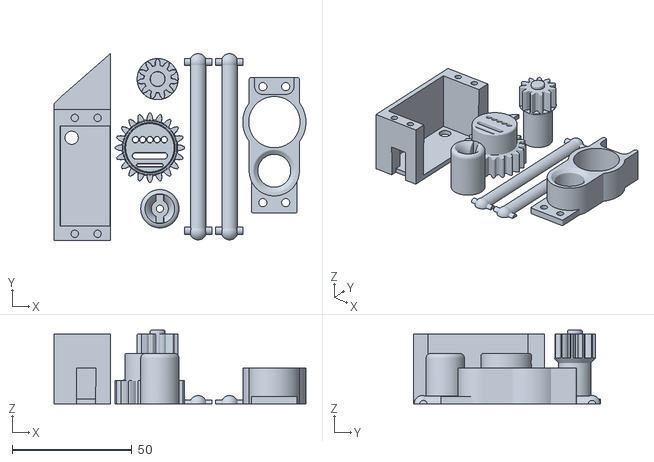
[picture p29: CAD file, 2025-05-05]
PLANOS STL/i2HandVicadel/i2_WristGearV1.stl
105.2 x 78.1 x 30.8

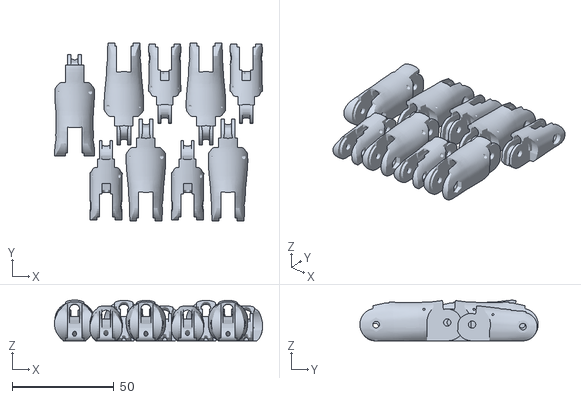
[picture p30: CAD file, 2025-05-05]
PLANOS STL/i2HandVicadel/i2_FingersX5V2.stl
102.3 x 87.7 x 20.0

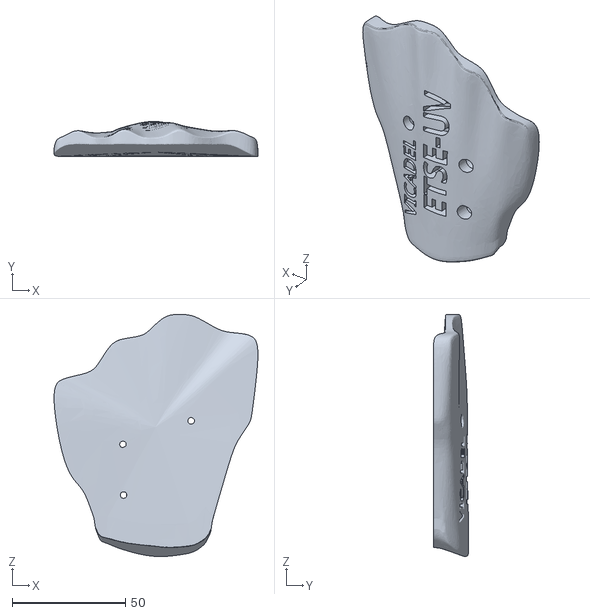
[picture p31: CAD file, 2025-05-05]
PLANOS STL/i2HandVicadel/Mano 2 ETSE.stl
90.2 x 15.6 x 107.0

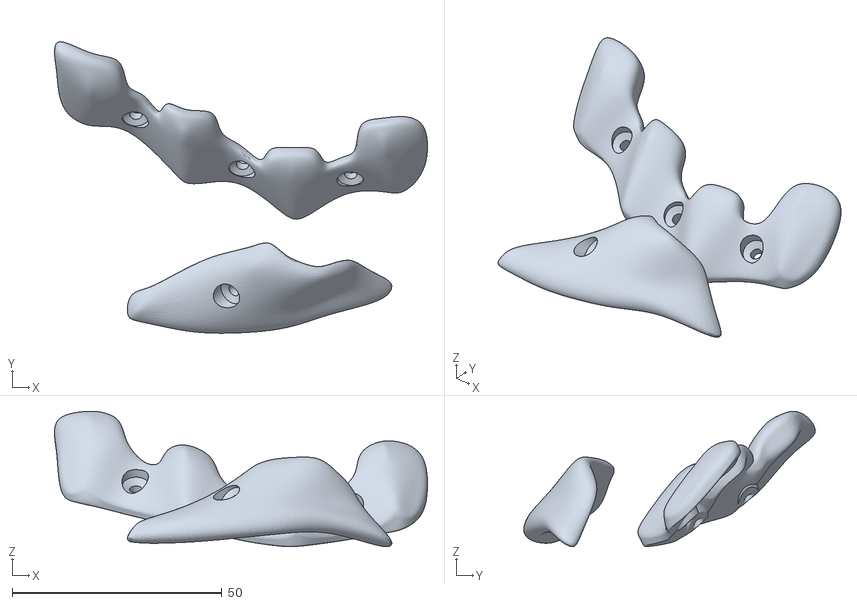
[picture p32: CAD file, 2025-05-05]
PLANOS STL/i2HandVicadel/i2_CoverFingerV3.stl
89.0 x 69.6 x 32.3

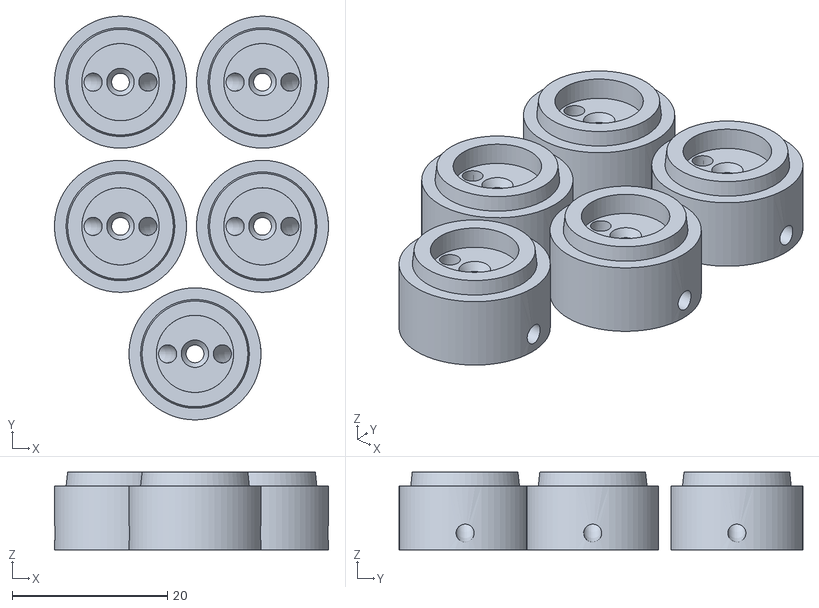
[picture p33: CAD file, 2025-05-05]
PLANOS STL/i2HandVicadel/i2_PulleyX5V1.stl
35.3 x 52.0 x 10.0

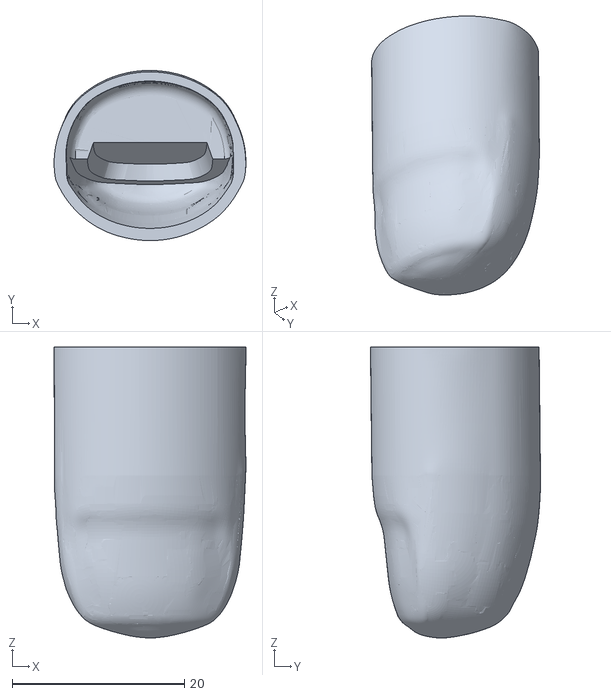
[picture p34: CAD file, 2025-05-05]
PLANOS STL/i2HandVicadel/Thumb_TipV2_with_shallow_magnet_hole.stl
22.3 x 19.8 x 33.8

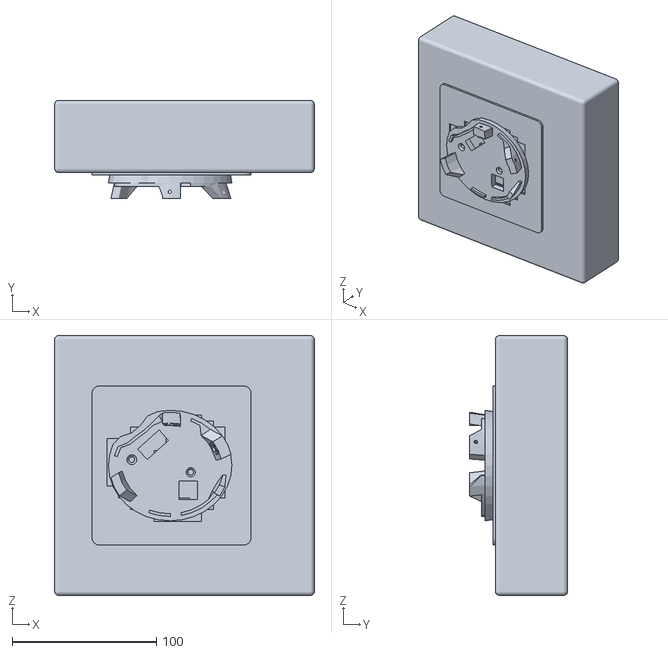
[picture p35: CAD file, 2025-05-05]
PLANOS STL/i2HandVicadel/BASE SOPORTE.stl
180.0 x 68.0 x 180.0

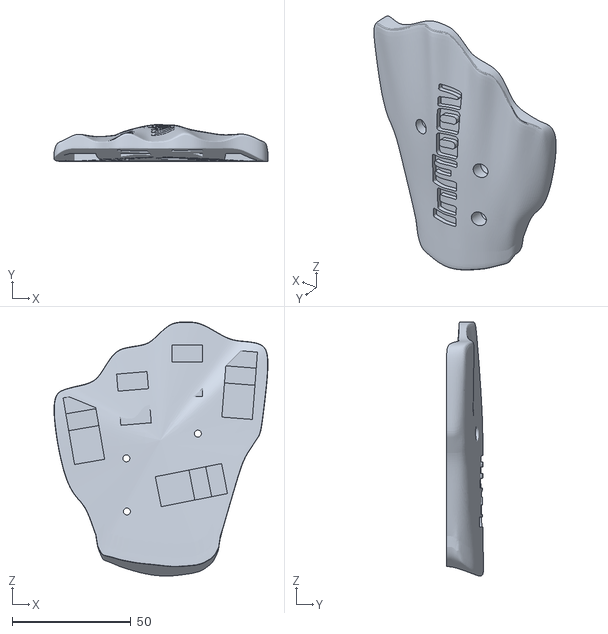
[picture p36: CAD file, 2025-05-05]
PLANOS STL/i2HandVicadel/i2_HandCoverV2.stl
90.2 x 15.6 x 107.1

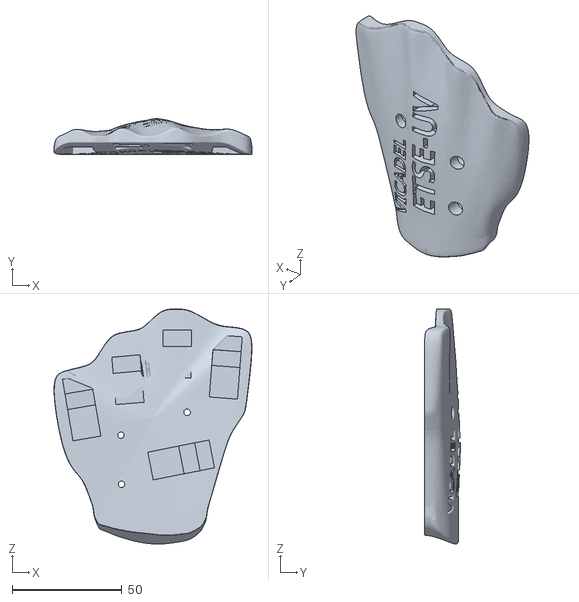
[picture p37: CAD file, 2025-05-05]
PLANOS STL/i2HandVicadel/Mano 1 ETSE.stl
90.2 x 16.3 x 107.1

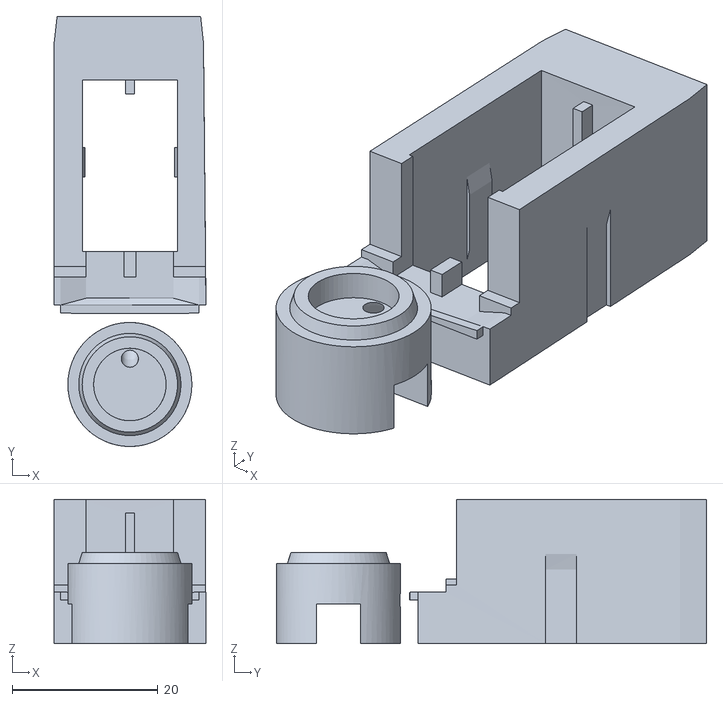
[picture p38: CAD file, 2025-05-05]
PLANOS STL/i2HandVicadel/i2_Adapter1109MG.stl
20.8 x 58.9 x 19.8

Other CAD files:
PLANOS STL/i2HandVicadel/i2_PalmPDI6225V3.stl
PLANOS STL/i2HandVicadel/i2_FingersMoldX5V3.stl
PLANOS STL/i2HandVicadel/i2_HandCoverV1.stl

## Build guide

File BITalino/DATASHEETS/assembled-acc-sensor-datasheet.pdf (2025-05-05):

# Accelerometer (ACC)

Assembled Sensor Data Sheet | BUNDLE-ACC-UCE6-Z/XYZ
| 221220

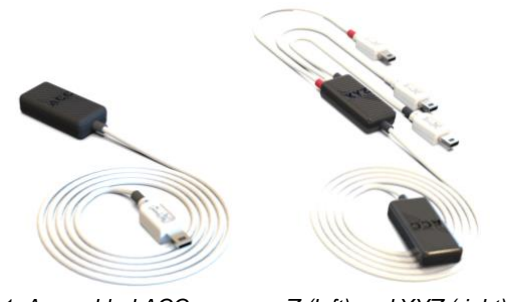
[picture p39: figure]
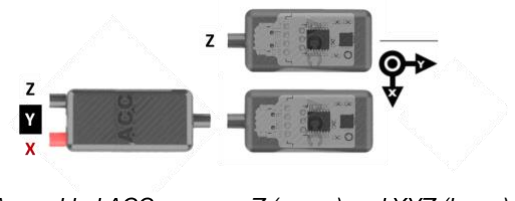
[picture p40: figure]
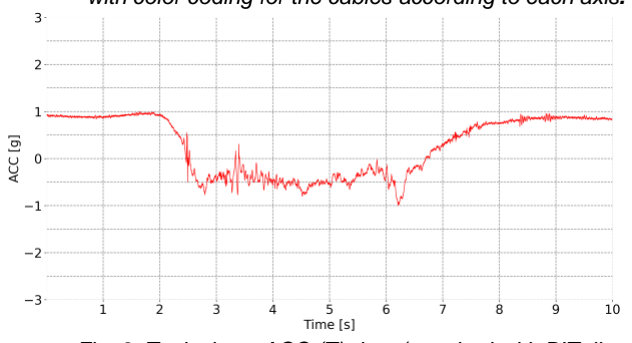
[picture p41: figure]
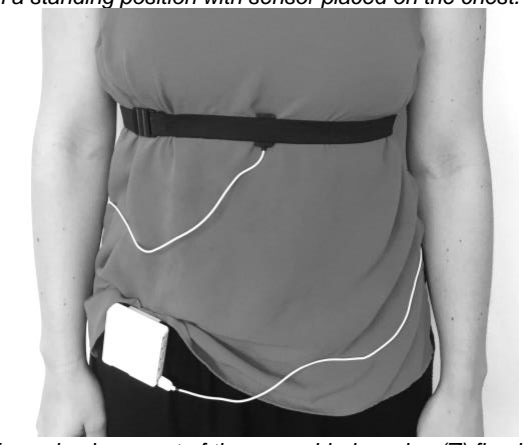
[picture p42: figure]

PLUX – Wireless Biosignals, S.A. Av. 5 de Outubro, n. 70 – 2 1050-059 Lisbon, Portugal
bitalino@plux.info
http://bitalino.com/

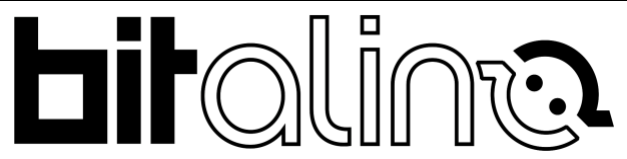
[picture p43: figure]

REV A | © 2020 PLUX

This information is provided "as is," and we make no express or implied warranties whatsoever with respect to functionality, operability, use, fitness for a particular purpose, or infringement of rights. We expressly disclaim any liability whatsoever for any direct, indirect, consequential, incidental or special damages, including, without limitation, lost revenues, lost profits, losses resulting from business interruption or loss of data, regardless of the form of action or legal theory under which the liability may be asserted, even if advised of the possibility of such damages.

BEWARE: DIRECT OR INDIRECT COUPLING TO THE MAINS MAY RESULT IN SHOCKING HAZARD

### SPECIFICATIONS > Pre-assembled Accelerometer (ACC) sensor Z or XYZ > Single cable connection (Z)

### FEATURES > Allows basic ACC data acquisition for one (Z) axis or three (XYZ) axes > Easy-to-use > Plug & play design > Raw data acquisition

### APPLICATIONS > Activity monitoring > Tilt detection > Vibration measurement > Human-Computer Interaction > Robotics & Cybernetics > Biomechanics > Biomedical devices prototyping

### GENERAL DESCRIPTION The BITalino assembled ACC sensor is designed for everyone who wants to

measure | movements | by | evaluating
Accelerometer | (ACC) | signals. | This

### bundle is completely assembled with our

3D | Printed | Casing | for | BITalino

### (r)evolution Plugged making it more convenient to use, wearable, sharable &

transportable. | The | Assembled

### Accelerometer (ACC) Sensors allow

repeatedly | accurate | & | fast

### measurements, once the user can benefit from the single cable connection for Z axis or the three cable connection

for XYZ axes.

Fig. 1. Assembled ACC sensor – Z (left) and XYZ (right).

Fig. 2. Assembled ACC sensor – Z (upper) and XYZ (lower) with color coding for the cables according to each axis.

Fig. 3. Typical raw ACC (Z) data (acquired with BITalino (r)evolution) performing a burpee with push up starting and ending in a standing position with sensor placed on the chest.

Fig. 4. Example placement of the assembled version (Z) fixed with a strap on the chest.

# Accelerometer (ACC) Assembled Sensor Data Sheet

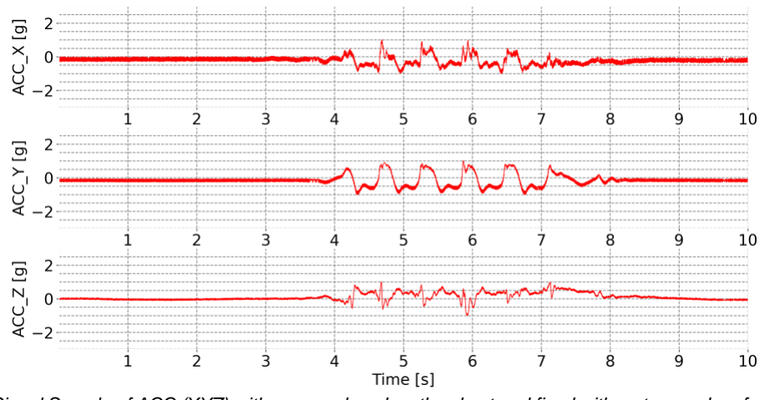
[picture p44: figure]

Fig. 5. Signal Sample of ACC (XYZ) with sensor placed on the chest and fixed with a strap and performing five consecutive jumps in Y-direction.

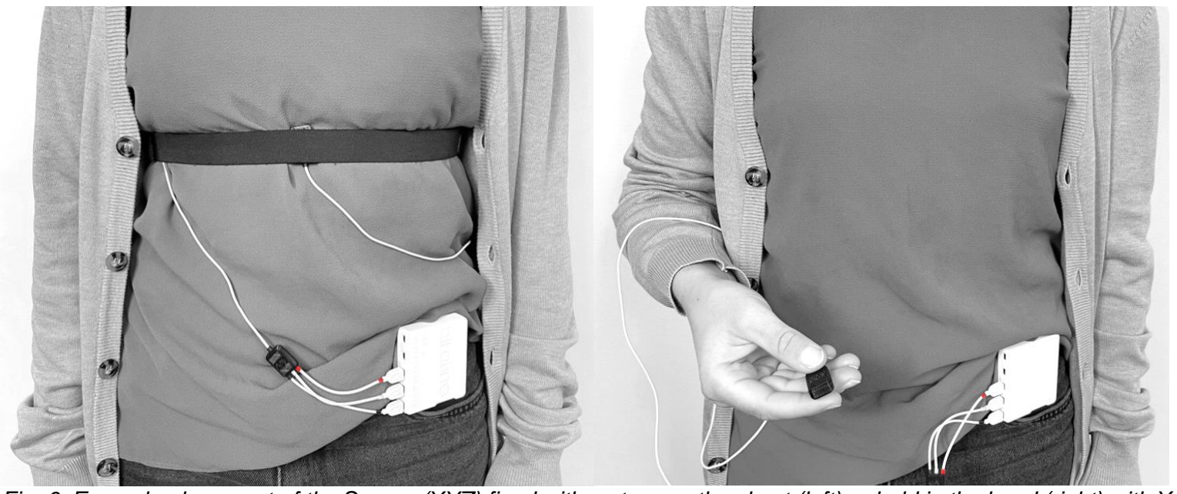
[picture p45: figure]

Fig. 6. Example placement of the Sensor (XYZ) fixed with a strap on the chest (left) or hold in the hand (right) with Xaxis in channel A3 (red), Y-axis in channel A2 (white) and Z-axis in channel A1 (black).

### TRANSFER FUNCTION

ACC datasheet (https://bitalino.com/storage/uploads/media/revolution-acc-sensor-datasheet-revb.pdf)

### PHYSICAL CHARACTERISTICS

ACC datasheet (https://bitalino.com/storage/uploads/media/revolution-acc-sensor-datasheet-revb.pdf)

### PACKAGING Weight: 9 g (Z)

### ORDERING GUIDE

Part # | Description
BUNDLE-ACC-UCE6-Z | The assembled version of a 3-axis accelerometer for motion measurement. This sensor is assembled with a 3D printed casing. Only the Z-axis is connected. Nevertheless, the user can choose to connect the X- and Y-axis following the procedure referred to in the datasheet.
BUNDLE-ACC-UCE6-XYZ | The assembled version of a 3-axis accelerometer for motion measurement. This sensor is assembled with a 3D printed casing. In this version, the XYZ-axis are connected and ready to be used.

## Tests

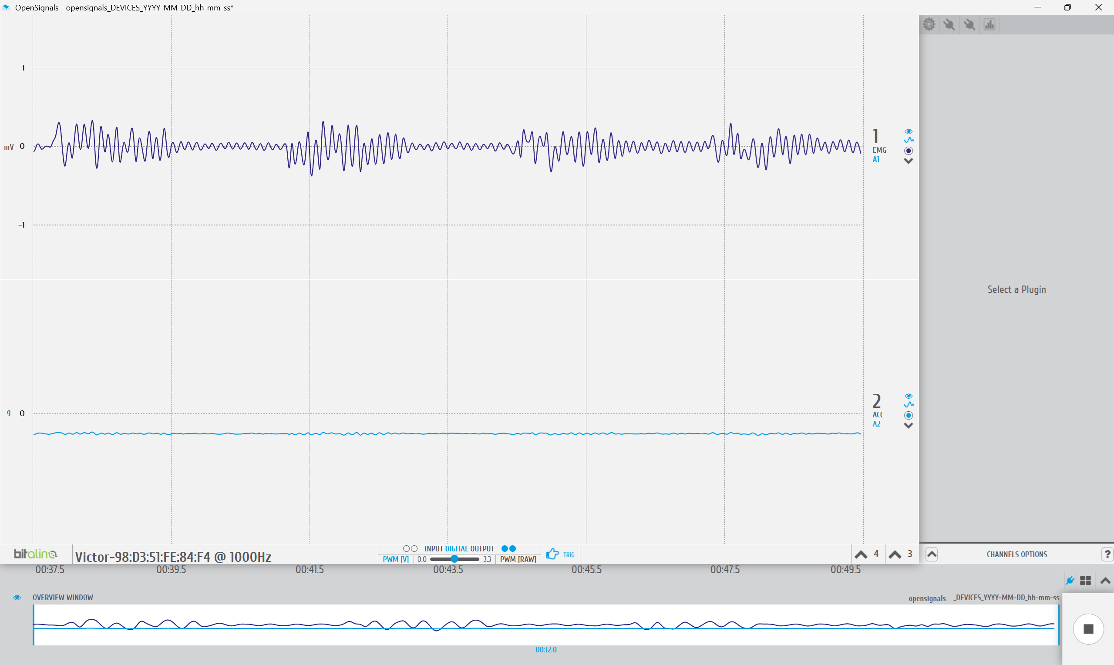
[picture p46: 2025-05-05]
BITalino/ExperimentalTests/EMG+ACC.png

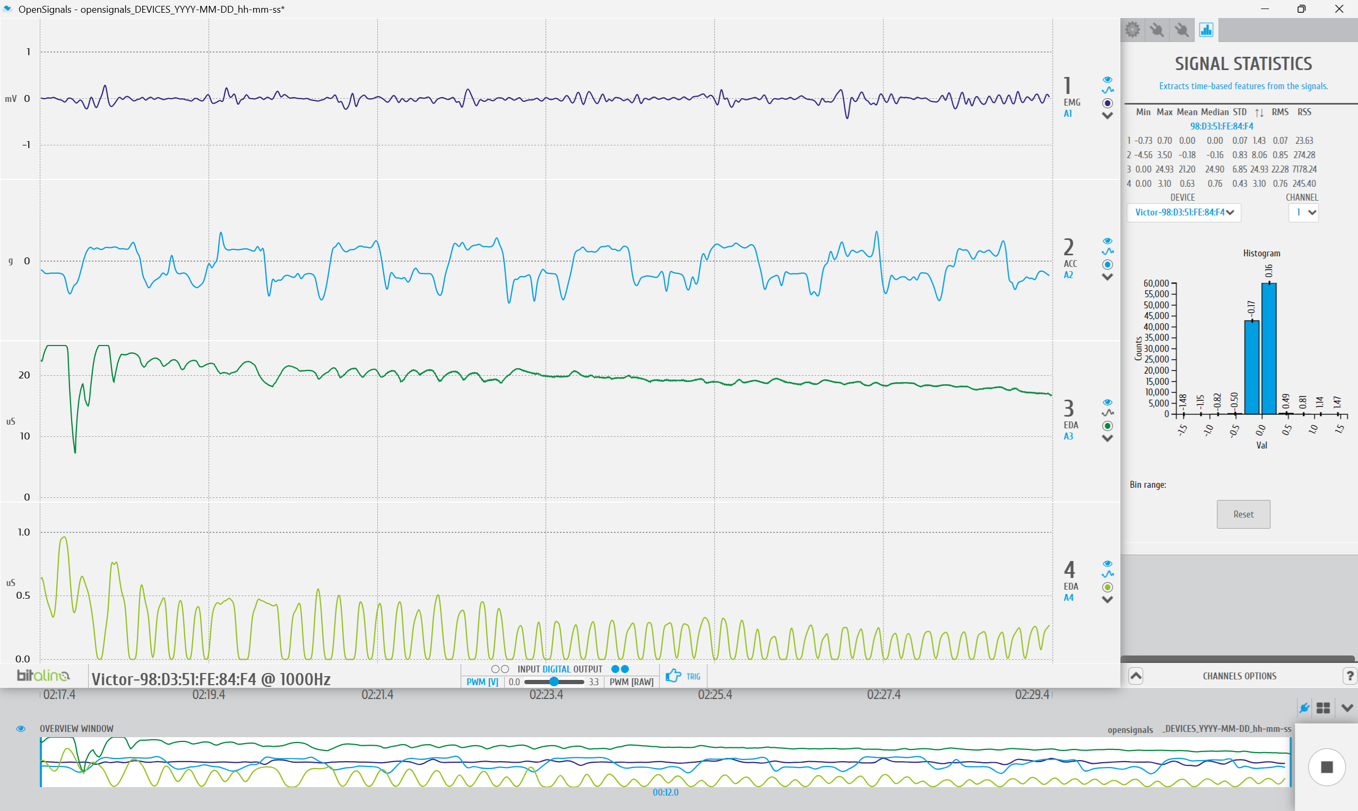
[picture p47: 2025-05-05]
BITalino/ExperimentalTests/EMG + ACC + EDA + BTN/EMG-EDA-ACC-BTN-ESTADISTICAS-BUENA-ANTEBRAZO.png

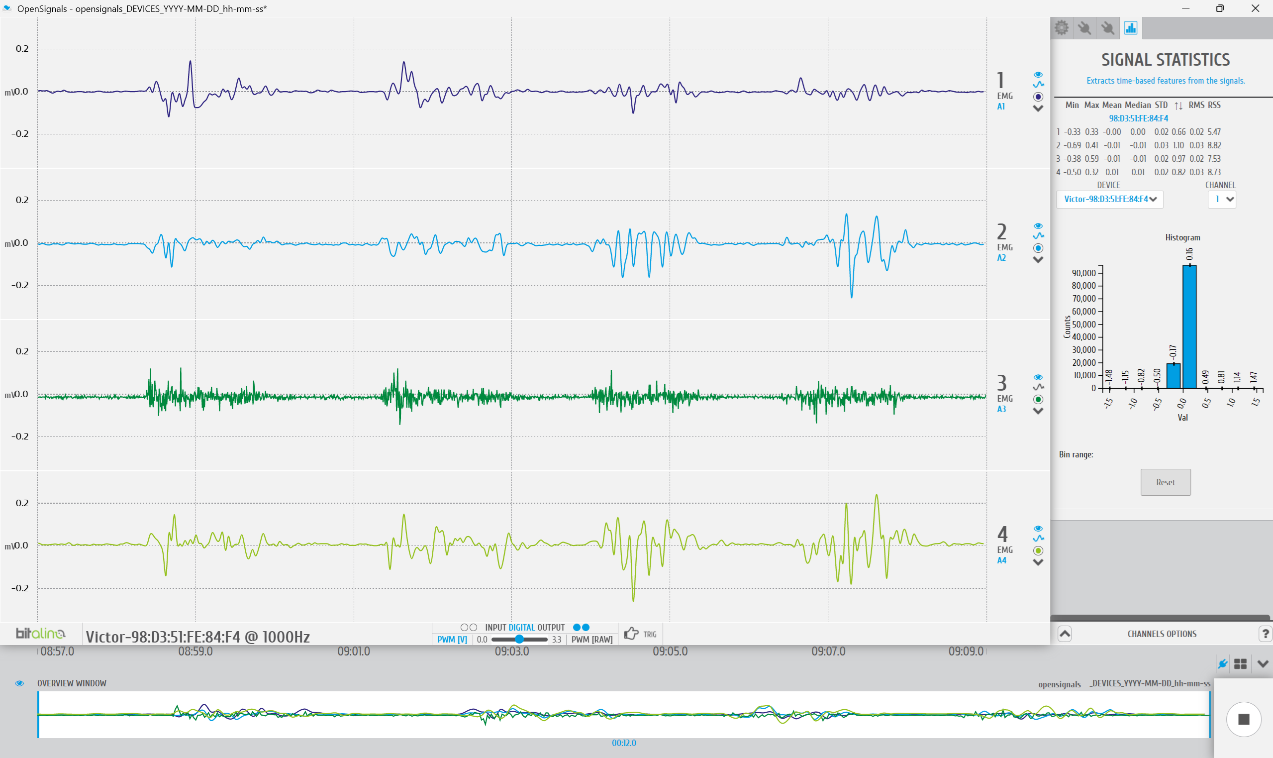
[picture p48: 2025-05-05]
BITalino/ExperimentalTests/PAZ--HECHA.png

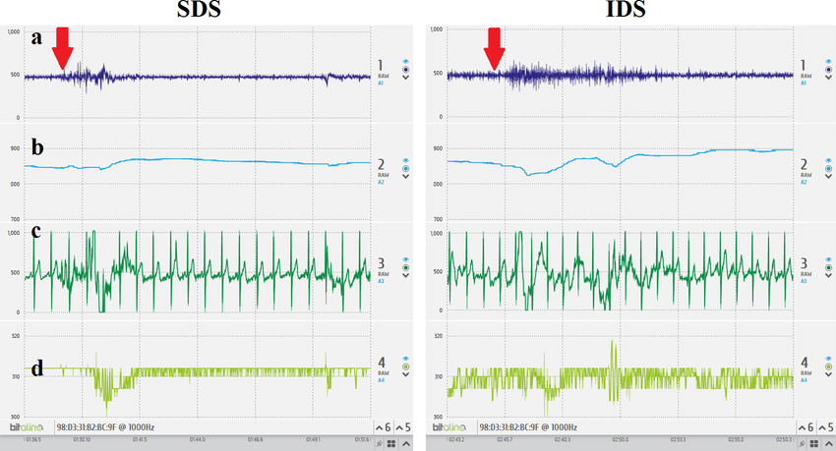
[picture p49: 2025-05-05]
BITalino/ExperimentalTests/EDA/Example-of-biosignals-recorded-with-BITalino-EMG-a-EDAb-ECG-c-and-accelerometer-d.png

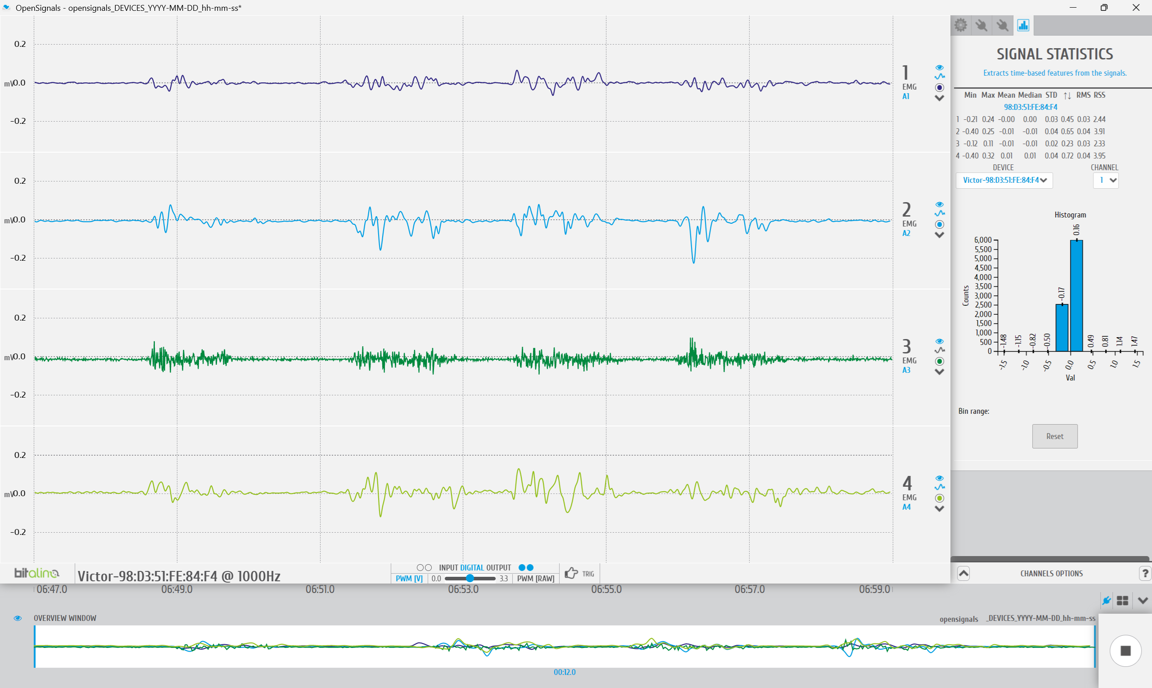
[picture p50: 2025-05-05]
BITalino/ExperimentalTests/SEÑALAR-HECHA.png

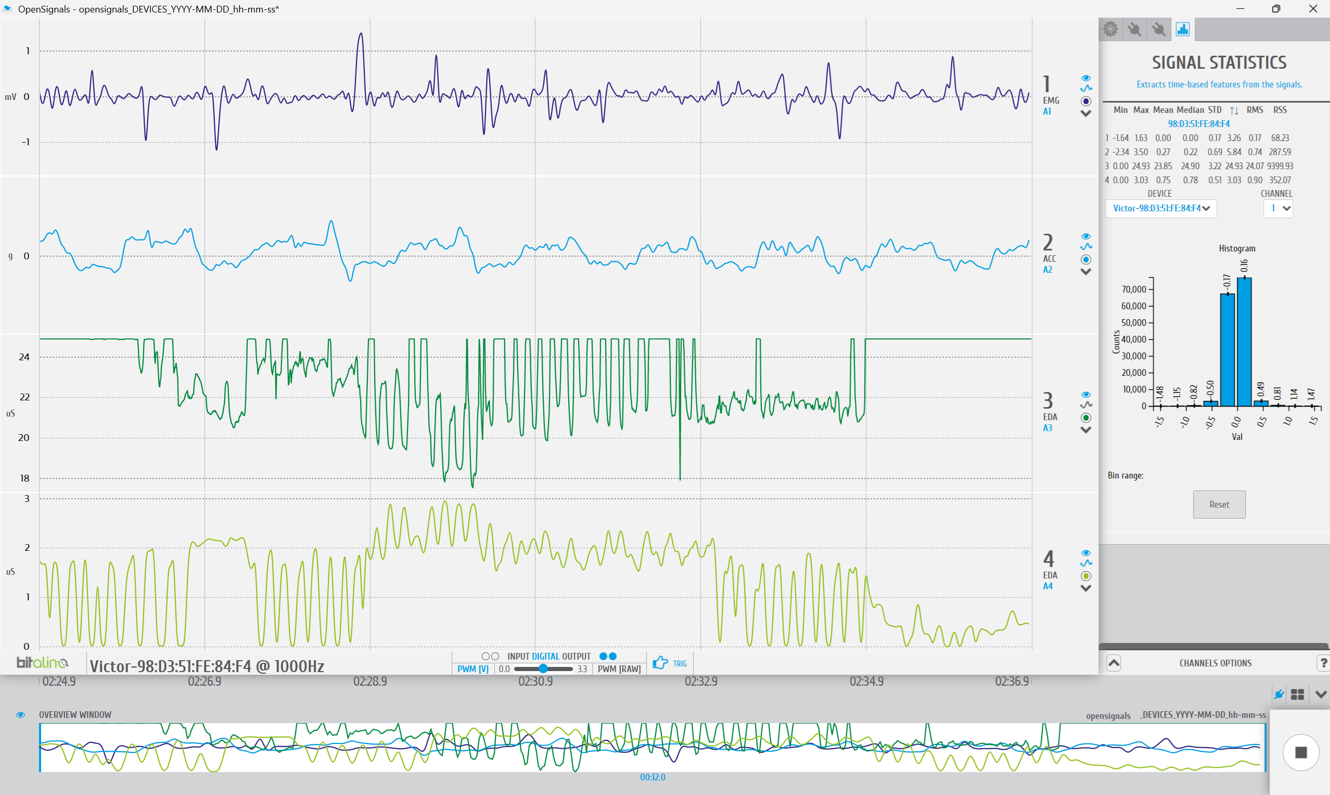
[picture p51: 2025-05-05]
BITalino/ExperimentalTests/EMG + ACC + EDA + BTN/EMG+EDA+ACC+BTN-ESTADISTICAS-HOMBRO-FINAL.png

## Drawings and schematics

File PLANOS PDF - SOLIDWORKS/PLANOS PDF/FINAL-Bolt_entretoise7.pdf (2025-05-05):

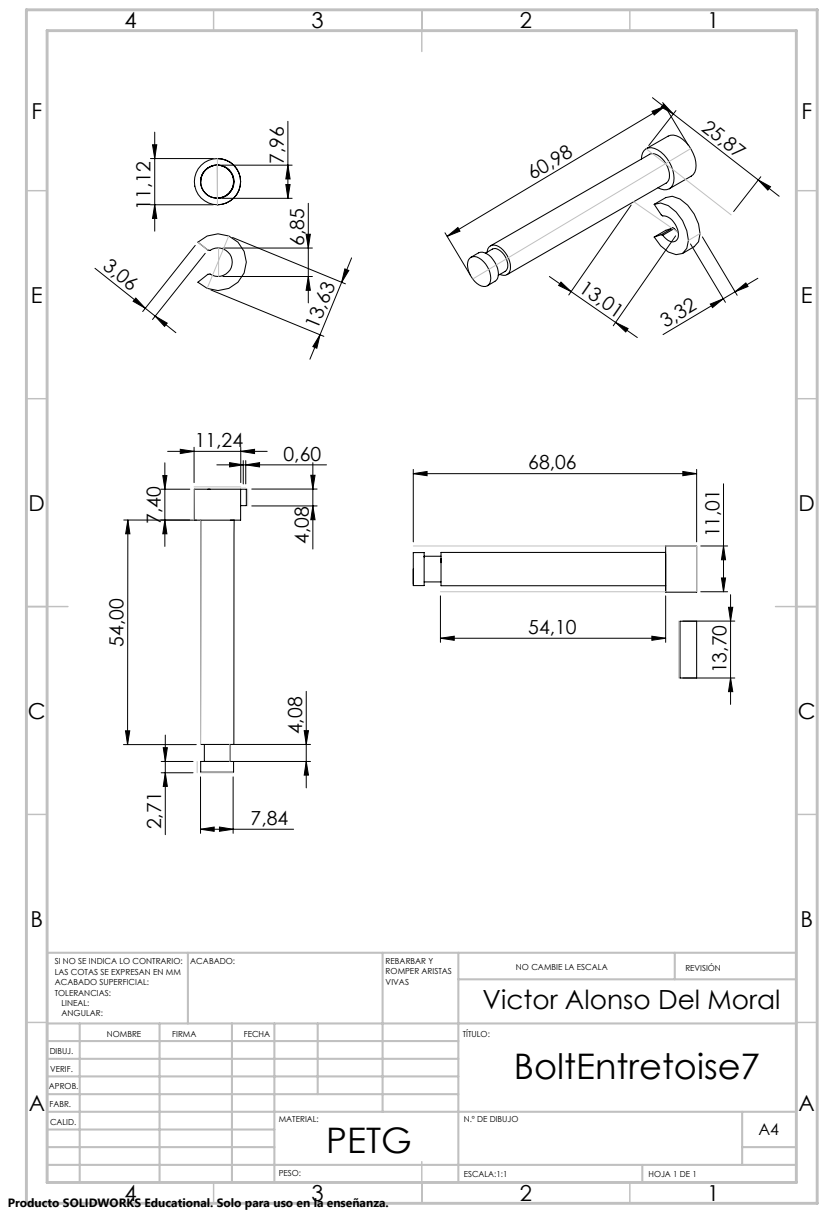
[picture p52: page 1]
ACABADO:; REBARBAR Y; ROMPER ARISTAS; NO CAMBIE LA ESCALA; REVISIÓN; ESCALA:1:1; HOJA 1 DE 1

SI NO SE INDICA LO CONTRARIO:
LAS COTAS SE EXPRESAN EN MM
ACABADO SUPERFICIAL:
TOLERANCIAS:
LINEAL:
ANGULAR:

Victor Alonso Del Moral

NOMBRE | FIRMA | FECHA | | | | TÍTULO: BoltEntretoise7

DIBUJ.
VERIF.
APROB.
FABR.
CALID. | | | | MATERIAL: PETG | N.º DE DIBUJO | A4

Producto SOLIDWORKS Educational. Solo para uso en la enseñanza.

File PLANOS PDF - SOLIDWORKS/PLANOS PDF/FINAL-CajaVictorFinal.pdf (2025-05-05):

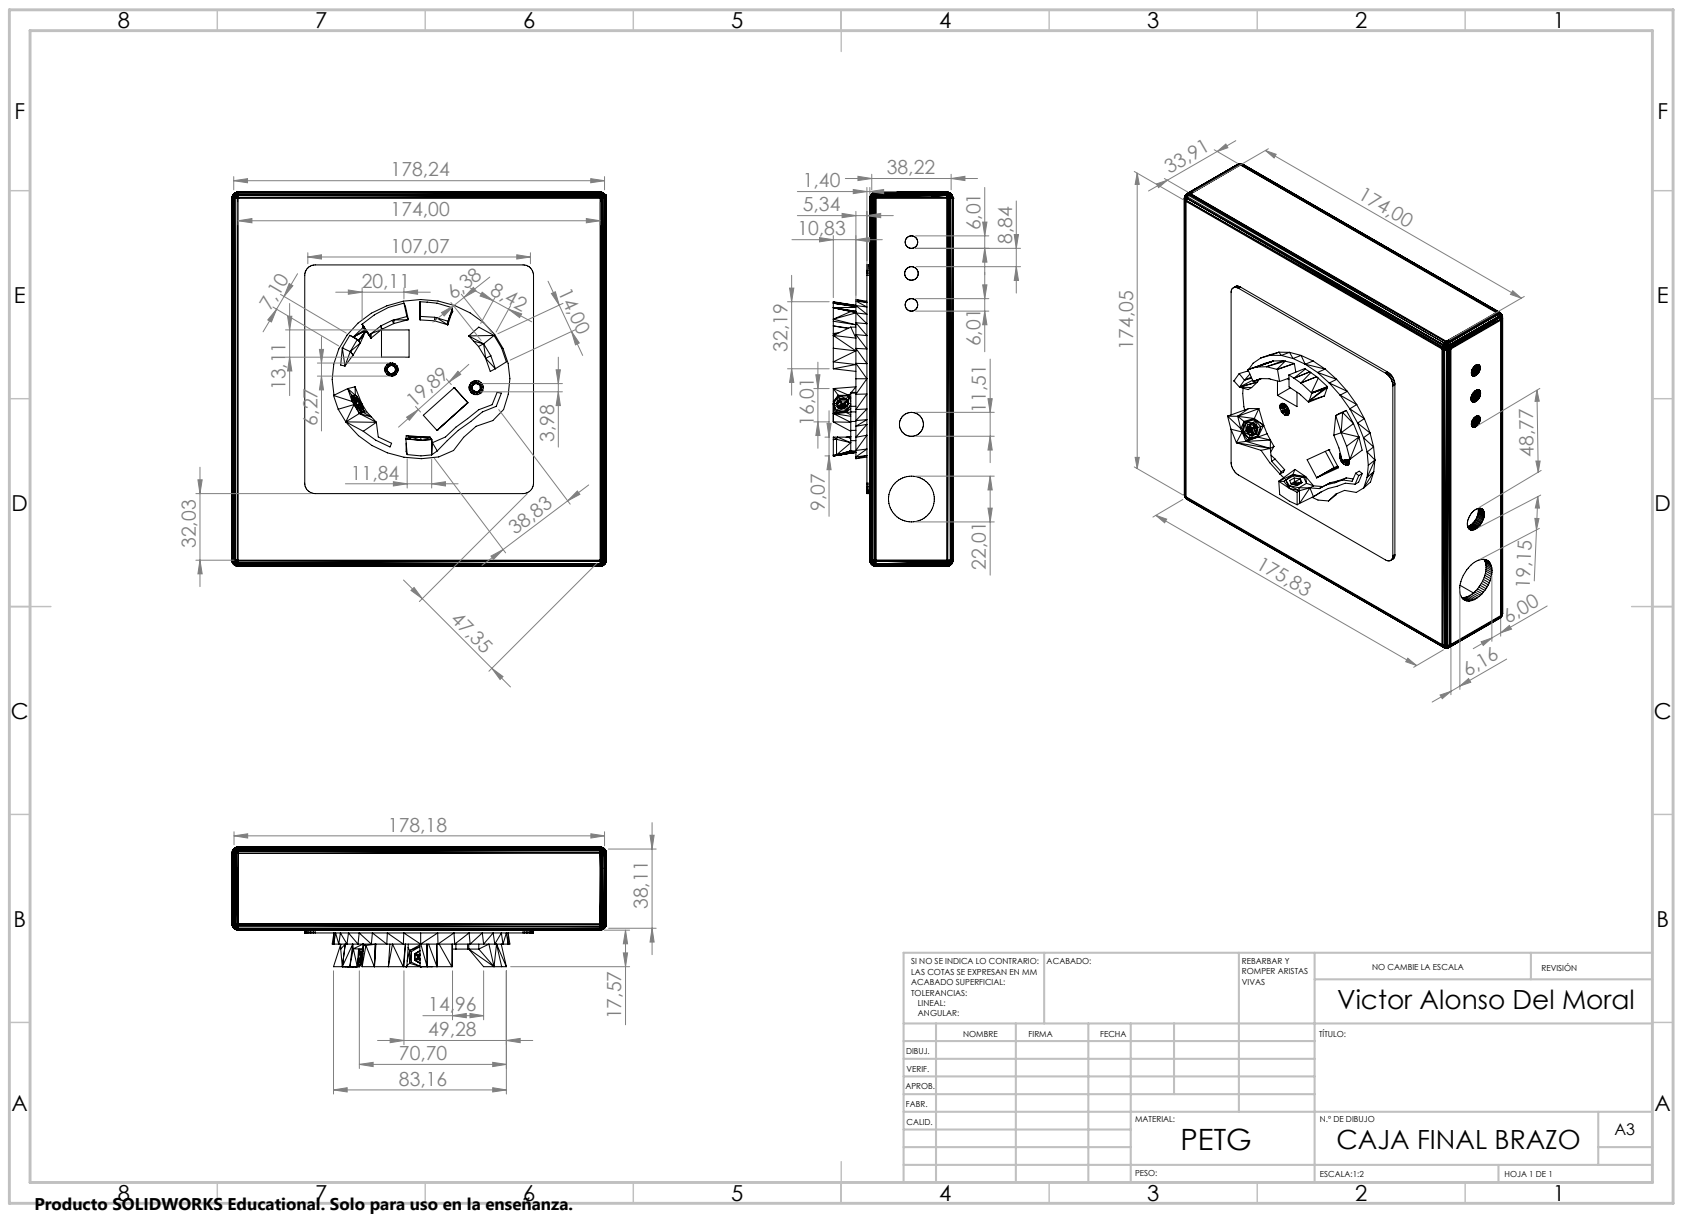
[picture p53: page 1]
ACABADO:; REBARBAR Y; ROMPER ARISTAS; NO CAMBIE LA ESCALA; REVISIÓN; ESCALA:1:2; HOJA 1 DE 1

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

Victor Alonso Del Moral

NOMBRE | FIRMA | FECHA | | | | TÍTULO:

DIBUJ.
VERIF.
APROB.
FABR.
CALID. | | | | MATERIAL: PETG | N.º DE DIBUJO CAJA FINAL BRAZO | A3

Producto SOLIDWORKS Educational. Solo para uso en la enseñanza.

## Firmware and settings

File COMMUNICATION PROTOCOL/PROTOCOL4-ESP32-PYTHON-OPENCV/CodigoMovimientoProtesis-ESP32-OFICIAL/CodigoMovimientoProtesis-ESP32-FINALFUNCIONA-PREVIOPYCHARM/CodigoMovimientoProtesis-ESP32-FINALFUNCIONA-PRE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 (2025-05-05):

// Incluye la librería ESP32Servo que permite controlar servomotores con un ESP32
#include <ESP32Servo.h>

// Definición de pines analógicos y digitales para el ESP32
#ifdef ESP32    

// Pines analógicos A0 - A7
#define A0 2
#define A1 4
#define A2 35
#define A3 34
#define A4 36
#define A5 39
#define A6 32
#define A7 33

// Pines digitales D2 - D13
#define D2 26
#define D3 25
#define D4 17
#define D5 16
#define D6 27
#define D7 14
#define D8 12
#define D9 13
#define D10 5
#define D11 23
#define D12 19
#define D13 18
#endif

// Definición de constantes para la comunicación serie
#define numOfValsRec 5   // Número de valores a recibir (uno por cada dedo)
#define digitsPerValRec 1 // Número de dígitos por valor

// Declaración de servos para cada dedo
Servo servoThumb;
Servo servoIndex;
Servo servoMiddle;
Servo servoRing;
Servo servoPinky;

// Variables para almacenar los valores recibidos
int valsRec[numOfValsRec];  // Array donde se almacenan los valores recibidos
int stringLength = numOfValsRec * digitsPerValRec + 1; // Longitud del mensaje recibido (Ejemplo: "$00000")
int counter = 0;         // Contador de caracteres recibidos
bool counterStart = false; // Indica si la recepción ha comenzado
String receivedString;    // Almacena el mensaje recibido

// Configuración inicial en setup()
void setup() {
    Serial.begin(9600);  // Inicia la comunicación serial a 9600 baudios

    // Asigna pines digitales a cada servo
    servoThumb.attach(D2);
    servoIndex.attach(D3);
    servoMiddle.attach(D4);
    servoRing.attach(D5);
    servoPinky.attach(D6);
}

// Función para recibir datos desde el Monitor Serie
void receiveData() {
    while (Serial.available()) // Si hay datos en el puerto serie
    {
        char c = Serial.read(); // Lee un carácter

        if (c == '$') {  // Si el carácter es '$', inicia la recepción de datos
            counterStart = true;
        }
        
        if (counterStart) { // Si la recepción ha iniciado
            if (counter < stringLength) { // Si aún faltan caracteres por recibir
                receivedString = String(receivedString + c); // Almacena el dato recibido
                counter++;
            }
        }
        
        if (counter >= stringLength) { // Cuando el mensaje está completo
            for (int i = 0; i < numOfValsRec; i++) // Extrae valores de los dedos
            {
                int num = (i * digitsPerValRec) + 1;
                valsRec[i] = receivedString.substring(num, num + digitsPerValRec).toInt();
            }
            receivedString = ""; // Borra la cadena recibida
            counter = 0;  // Reinicia el contador
            counterStart = false; // Indica que se ha terminado la recepción
        }
    }
}

// Bucle principal
void loop() {
    receiveData();  // Llama a la función que recibe los datos desde el puerto serie

    // Control de los servos según los valores recibidos
    if (valsRec[0] == 1) {servoThumb.write(180);} else {servoThumb.write(0);}  // Pulgar
    if (valsRec[1] == 1) {servoIndex.write(180);} else {servoIndex.write(0);}  // Índice
    if (valsRec[2] == 1) {servoMiddle.write(180);} else {servoMiddle.write(0);}  // Medio
    if (valsRec[3] == 1) {servoRing.write(180);} else {servoRing.write(0);}  // Anular
    if (valsRec[4] == 1) {servoPinky.write(180);} else {servoPinky.write(0);}  // Meñique
}

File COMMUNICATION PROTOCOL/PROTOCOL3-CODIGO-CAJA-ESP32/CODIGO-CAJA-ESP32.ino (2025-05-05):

//Script to control InMoov Arm using Aoutecen EMG Muscle Sensor V3 from Advancer Technologies
//by Victor Alonso (vicadel@alumni.uv.es)
//Valencia (Spain)
//Juny 2025
//Part of TFG 3D Prostetic Hand & Forarm - InMoov Project 

//For information about Aoutecen EMG Muscle Sensor V3 board, manual and other resources, please visit:
//https://www.tme.eu/Document/8732078ad54d82f6b49c5284341026b5/POLOLU-2726.pdf


/*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
 * You should have received a copy of the GNU General Public License
 * along with this program.  If not, see <http://www.gnu.org/licenses/>.
 * */


// === Librerías necesarias ===
#include <ESP32Servo.h>  // Para controlar servos con ESP32

// === Definición de pines ===
#define D2 26  // Pulgar
#define D3 25  // Índice
#define D4 17  // Medio
#define D5 16  // Anular
#define D6 27  // Meñique

#define D7 14  // (Reservado para la muñeca si se usa)

#define RLED 12   // LED rojo
#define BLED 13   // LED azul
#define PUSH 8    // Botón pulsador rojo
#define SWITCH 9  // Interruptor de modo

#define RXD1 10   // Bluetooth RX (conectado al TX del módulo)
#define TXD1 11   // Bluetooth TX (conectado al RX del módulo)

// === Objetos servo con nombres reutilizados ===
Servo servo_thumb;    // Pulgar
Servo servo_index;    // Índice
Servo servo_middle;   // Medio
Servo servo_ring;     // Anular
Servo servo_pinky;    // Meñique

// === Variables para guardar la posición actual de cada dedo ===
int ThumbPos = 45;
int IndexPos = 45;
int MiddlePos = 45;
int RingPos = 45;
int LittlePos = 45;

// === Velocidades de movimiento ===
int fingerSpeed = 20;  // Velocidad para dedos individuales
int HandSpeed = 20;    // Velocidad para toda la mano

void setup() {
  // Inicializamos el puerto serie para Bluetooth en UART1
  Serial1.begin(9600, SERIAL_8N1, RXD1, TXD1);  // RX, TX

  // Configuramos pines de LED y botones
  pinMode(RLED, OUTPUT);
  pinMode(BLED, OUTPUT);
  pinMode(PUSH, INPUT_PULLUP);
  pinMode(SWITCH, INPUT_PULLUP);

  // Asociamos cada servo a su pin correspondiente
  servo_thumb.attach(D2);
  servo_index.attach(D3);
  servo_middle.attach(D4);
  servo_ring.attach(D5);
  servo_pinky.attach(D6);

  // Inicializamos todos los dedos en posición neutral (45°)
  servo_thumb.write(ThumbPos);
  servo_index.write(IndexPos);
  servo_middle.write(MiddlePos);
  servo_ring.write(RingPos);
  servo_pinky.write(LittlePos);

  // Apagamos ambos LEDs al inicio
  digitalWrite(RLED, LOW);
  digitalWrite(BLED, LOW);
}

void loop() {
  // Leemos el estado del interruptor
  int ProgSwitch = digitalRead(SWITCH);

  // Si el switch está en modo pulsador
  if (ProgSwitch == 0) {
    PUSH_BUTTON();
    digitalWrite(RLED, LOW);
    digitalWrite(BLED, HIGH);
  }
  // Si el switch está en modo Bluetooth
  else {
    BLUETOOTH();
    digitalWrite(RLED, HIGH);
    digitalWrite(BLED, LOW);
  }
}

// === Función para controlar los dedos con el botón físico ===
void PUSH_BUTTON() {
  int PushState = digitalRead(PUSH);

  if (PushState == 0) {
    // Si todos los dedos están en 45°, los cerramos
    if (ThumbPos == 45 && IndexPos == 45 && MiddlePos == 45 && RingPos == 45 && LittlePos == 45) {
      for (int i = 45; i <= 150; i++) {
        servo_index.write(i);
        servo_middle.write(i);
        servo_ring.write(i);
        servo_pinky.write(i);

        IndexPos = i;
        MiddlePos = i;
        RingPos = i;
        LittlePos = i;

        delay(HandSpeed);
      }

      for (int i = 45; i <= 150; i++) {
        servo_thumb.write(i);
        ThumbPos = i;
        delay(HandSpeed);
      }
    }
    // Si todos los dedos están cerrados (150°), los abrimos
    else if (ThumbPos == 150 && IndexPos == 150 && MiddlePos == 150 && RingPos == 150 && LittlePos == 150) {
      for (int i = 150; i >= 45; i--) {
        servo_thumb.write(i);
        ThumbPos = i;
        delay(HandSpeed);
      }

      for (int i = 150; i >= 45; i--) {
        servo_index.write(i);
        servo_middle.write(i);
        servo_ring.write(i);
        servo_pinky.write(i);

        IndexPos = i;
        MiddlePos = i;
        RingPos = i;
        LittlePos = i;

        delay(HandSpeed);
      }
    }
  }
  else {
    // Si no se pulsa, los dedos se mantienen en su posición actual
    servo_thumb.write(ThumbPos);
    servo_index.write(IndexPos);
    servo_middle.write(MiddlePos);
    servo_ring.write(RingPos);
    servo_pinky.write(LittlePos);
  }
}

// === Función para controlar la mano por Bluetooth ===
void BLUETOOTH() {
  if (Serial1.available()) {
    char data = Serial1.read();  // Lee el carácter recibido

    // === Control por letra recibida ===
    if (data == 'T') toggleFinger(servo_thumb, ThumbPos);
    else if (data == 'I') toggleFinger(servo_index, IndexPos);
    else if (data == 'M') toggleFinger(servo_middle, MiddlePos);
    else if (data == 'R') toggleFinger(servo_ring, RingPos);
    else if (data == 'L') toggleFinger(servo_pinky, LittlePos);

    // === Comando 'H' para abrir/cerrar toda la mano ===
    else if (data == 'H') {
      if (ThumbPos == 45 && IndexPos == 45 && MiddlePos == 45 && RingPos == 45 && LittlePos == 45) {
        // Cerramos todos los dedos menos el pulgar
        for (int i = 45; i <= 150; i++) {
          servo_index.write(i);
          servo_middle.write(i);
          servo_ring.write(i);
          servo_pinky.write(i);
          IndexPos = i;
          MiddlePos = i;
          RingPos = i;
          LittlePos = i;
          delay(HandSpeed);
        }

        // Luego cerramos el pulgar
        for (int i = 45; i <= 150; i++) {
          servo_thumb.write(i);
          ThumbPos = i;
          delay(HandSpeed);
        }
      }
      else if (ThumbPos == 150 && IndexPos == 150 && MiddlePos == 150 && RingPos == 150 && LittlePos == 150) {
        // Abrimos primero el pulgar
        for (int i = 150; i >= 45; i--) {
          servo_thumb.write(i);
          ThumbPos = i;
          delay(HandSpeed);
        }

        // Luego el resto de dedos
        for (int i = 150; i >= 45; i--) {
          servo_index.write(i);
          servo_middle.write(i);
          servo_ring.write(i);
          servo_pinky.write(i);
          IndexPos = i;
          MiddlePos = i;
          RingPos = i;
          LittlePos = i;
          delay(HandSpeed);
        }
      }
      else {
        Serial1.println("Err: Position of all fingers are not same");
      }
    }
  }
}

// === Función auxiliar para abrir/cerrar un dedo desde Bluetooth ===
void toggleFinger(Servo &servo, int &pos) {
  if (pos == 45) {
    for (int i = 45; i <= 150; i++) {
      servo.write(i);
      pos = i;
      delay(fingerSpeed);
    }
  } else {
    for (int i = 150; i >= 45; i--) {
      servo.write(i);
      pos = i;
      delay(fingerSpeed);
    }
  }
}

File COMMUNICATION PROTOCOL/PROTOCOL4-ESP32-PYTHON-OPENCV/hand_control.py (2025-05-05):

import cv2
import mediapipe as mp
import time
import serial

class HandDetector():
    def __init__(self, mode=False, maxHands=2, detectionCon=0.5, trackCon=0.5):
        self.mode = mode
        self.maxHands = maxHands
        self.detectionCon = detectionCon
        self.trackCon = trackCon

        self.mpHands = mp.solutions.hands
        self.hands = self.mpHands.Hands(static_image_mode=mode,
                                        max_num_hands=maxHands,
                                        min_detection_confidence=detectionCon,
                                        min_tracking_confidence=trackCon)
        self.mpDraw = mp.solutions.drawing_utils

    def findHands(self, frame, draw=True):
        imgRGB = cv2.cvtColor(frame, cv2.COLOR_BGR2RGB)
        self.results = self.hands.process(imgRGB)

        if self.results.multi_hand_landmarks:
            for handLms in self.results.multi_hand_landmarks:
                if draw:
                    self.mpDraw.draw_landmarks(frame, handLms, self.mpHands.HAND_CONNECTIONS)
        return frame

    def findPosition(self, frame, handNo=0, draw=False):
        lmList = []
        if self.results.multi_hand_landmarks:
            myHand = self.results.multi_hand_landmarks[handNo]
            for id, lm in enumerate(myHand.landmark):
                h, w, c = frame.shape
                cx, cy = int(lm.x * w), int(lm.y * h)
                lmList.append([id, cx, cy])
                if draw and id == 0:
                    cv2.circle(frame, (cx, cy), 15, (255, 0, 0), cv2.FILLED)
        return lmList

def main():
    prevTime = 0
    currentTime = 0
    hand = [["Wrist", False], ["Index", False], ["Middle", False], ["Ring", False], ["Thumb", False], ["Pinky", False]]

    ser = serial.Serial(port="COM3", baudrate=9600)  # ⚠️ Cambia "COM3" por el puerto correcto de tu ESP32
    cap = cv2.VideoCapture(0, cv2.CAP_DSHOW)
    detector = HandDetector()

    while True:
        ret, frame = cap.read()
        frame = detector.findHands(frame)
        lmList = detector.findPosition(frame)

        if len(lmList) > 0:
            j = 1
            change = False
            for i in range(1, 6):
                if i == 1:
                    if lmList[4][1] < lmList[3][1]:
                        hand[4][1] = True
                        change = True
                        print(hand[4][0], hand[4][1])
                    else:
                        hand[4][1] = False
                        change = True
                        print(hand[4][0], hand[4][1])
                else:
                    if lmList[i*4][2] > lmList[(i*4)-2][2]:
                        hand[j][1] = True
                        change = True
                        print(hand[j][0], hand[j][1])
                    else:
                        hand[j][1] = False
                        change = True
                        print(hand[j][0], hand[j][1])
                    j = j+1 if j != 3 else j+2

            if change:
                msg = ""
                for i in range(6):
                    msg += "1" if hand[i][1] else "0"
                msg += '\n'
                print(msg)
                ser.write(msg.encode("ascii"))

        currentTime = time.time()
        fps = 1/(currentTime - prevTime)
        prevTime = currentTime
        cv2.putText(frame, str(int(fps)), (10, 70), cv2.FONT_HERSHEY_SIMPLEX, 1, (0, 255, 0), 3)
        cv2.imshow("frame", frame)

        if cv2.waitKey(1) & 0xFF == ord("q"):
            break

    cap.release()
    cv2.destroyAllWindows()

main()

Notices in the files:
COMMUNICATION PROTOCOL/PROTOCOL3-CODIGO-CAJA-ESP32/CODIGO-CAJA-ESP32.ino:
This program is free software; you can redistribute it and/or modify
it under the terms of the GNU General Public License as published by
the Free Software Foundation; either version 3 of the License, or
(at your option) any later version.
